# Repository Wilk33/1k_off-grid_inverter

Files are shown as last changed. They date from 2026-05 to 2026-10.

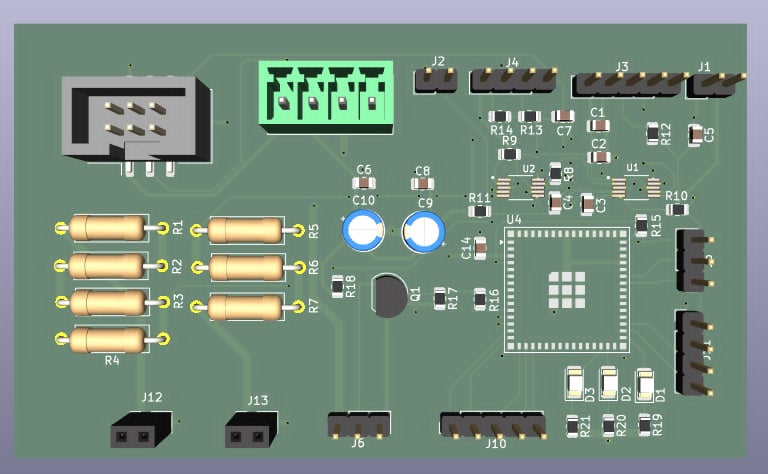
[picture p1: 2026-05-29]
hardware/MCU_measurements/pcb_kicad_3d.png

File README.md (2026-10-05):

# Off-Grid 1kW Inverter (24V DC -> 230V AC)

> [!IMPORTANT]
> **Projekt został zamknięty i nie będzie dalej rozwijany.**
>
> Repozytorium pozostaje archiwum dotychczasowego kodu i dokumentacji. Nie są planowane kolejne etapy, poprawki ani nowe wydania.

Projekt przetwornicy off-grid o mocy 1 kW przeznaczonej do konwersji napięcia z instalacji 24V DC na napięcie sieciowe 230V AC 50Hz.
Urządzenie składa się z dwóch głównych stopni konwersji energii:

1. Przetwornica DC/DC podwyższająca napięcie z 24V do około 325V DC
2. Falownik DC/AC generujący napięcie 230V AC 50Hz

System sterowany jest przez mikrokontroler odpowiedzialny za generację sygnałów sterujących, pomiary oraz zabezpieczenia.

---

# Główne parametry

| Parametr | Wartość |
| --- | --- |
| Moc znamionowa | 1000W |
| Napięcie wejściowe | 24V DC |
| Napięcie pośrednie | ~325V DC |
| Napięcie wyjściowe | 230V AC |
| Częstotliwość | 50Hz |
| Typ pracy | Off-grid |
| Sterowanie | Mikrokontroler |

---

# Architektura systemu

System składa się z kilku głównych bloków funkcjonalnych:

24V DC
↓
DC/DC Boost Converter
↓
325V DC Bus
↓
Full Bridge Inverter
↓
LC Filter
↓
230V AC 50Hz

Dodatkowo system zawiera:

* sterowniki bramek tranzystorów mocy
* układy pomiarowe prądu i napięcia
* system chłodzenia

---

# Moduły projektu

## 1. Przetwornica DC/DC (24V -> 325V)

Odpowiada za podwyższenie napięcia z poziomu akumulatora do napięcia magistrali DC.

Główne elementy:

* transformator wysokiej częstotliwości
* tranzystory MOSFET
* sterowniki bramek

---

## 2. Falownik (325V DC -> 230V AC)

Falownik generuje napięcie sinusoidalne poprzez modulację PWM.

Topologia:

Full Bridge (H-Bridge)

Sterowanie:

SPWM (Sinusoidal Pulse Width Modulation)

Elementy:

* tranzystory MOSFET / IGBT
* drivery bramek
* filtr LC

---

## 3. Mikrokontroler

Mikrokontroler jest centralną jednostką sterującą systemem.

Zadania:

* generowanie sygnałów PWM
* sterowanie przetwornicą DC/DC
* sterowanie falownikiem
* pomiar napięcia i prądu
* implementacja zabezpieczeń
* diagnostyka systemu

---

## 4. Sterowniki elementów mocy

Sterowniki bramek odpowiadają za szybkie i bezpieczne przełączanie tranzystorów.

Wymagania:

* izolacja galwaniczna
* odpowiedni prąd sterowania bramki
* kontrola dead-time
* ochrona przed zwarciem

---

## 5. Pomiar prądu i napięcia

Układ pomiarowy pozwala na monitorowanie parametrów pracy systemu.

Pomiar obejmuje:

* napięcie wejściowe
* napięcie magistrali DC
* napięcie wyjściowe AC
* prąd wyjściowy

Stosowane elementy:

* rezystory pomiarowe
* czujniki Halla
* dzielniki napięcia

---

## 6. Konstrukcja mechaniczna

Projekt mechaniczny obejmuje:

* obudowę
* system chłodzenia
* rozmieszczenie PCB
* radiatory dla elementów mocy

---

# Struktura repozytorium

```
hardware/ 
    dcdc_converter/
    drivers/
    inverter/
    measurements/

firmware/
    mcu_control/
    pwm_generation/
    measurements/
    protection/
```

---

# Etapy projektu

1. Projekt architektury systemu
2. Projekt przetwornicy DC/DC
3. Projekt falownika
4. Implementacja firmware mikrokontrolera
5. Projekt PCB

---

# Licencja

Projekt open hardware / open source.

---

# Autorstwo i status

Projekt był tworzony przez Codex GPT-5.6-Sol pod kierunkiem Mateusza Skipora, na podstawie jego wymagań i decyzji projektowych.

Status końcowy: projekt zamknięty, bez dalszego rozwoju.

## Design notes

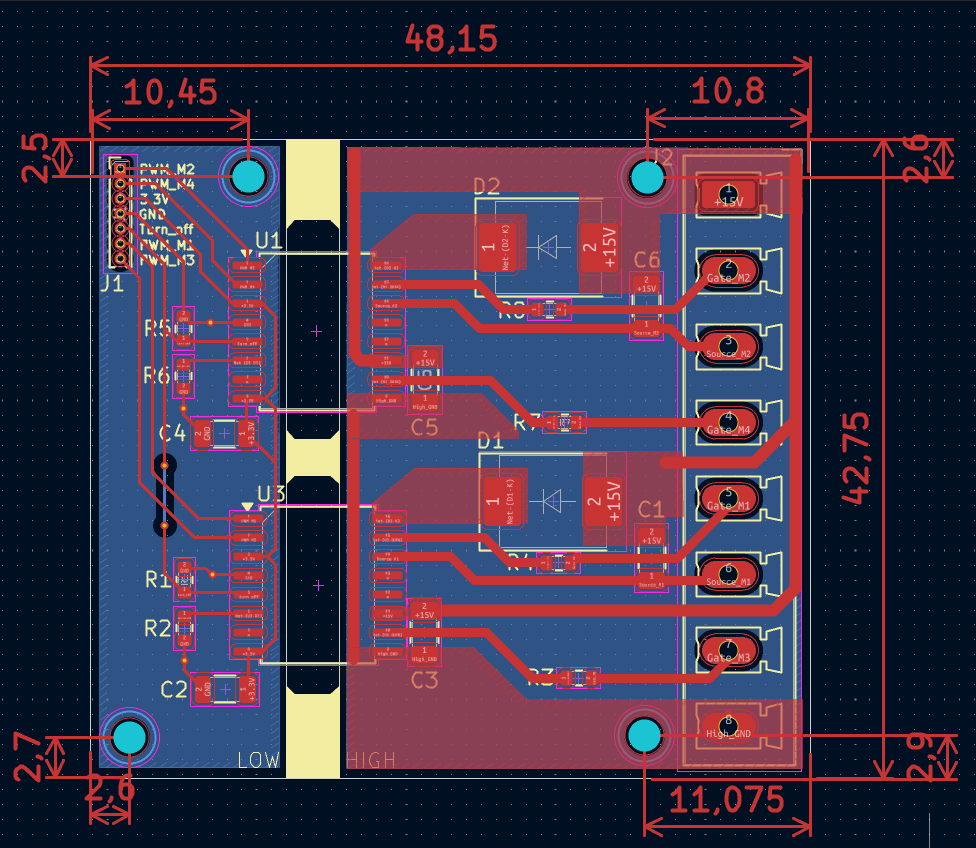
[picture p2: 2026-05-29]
hardware/drivers/Wymiary.png

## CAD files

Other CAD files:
hardware/MCU_measurements/projekt falownik/falownik.f3d

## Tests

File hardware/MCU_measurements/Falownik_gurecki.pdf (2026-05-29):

## Dokumentacja techniczna projektu

# Falownik off-grid 1 kW

## 24 V DC - 230 V AC 50 Hz

Scrum Master: | Mateusz Skipor
Project Owner: | Jakub Wacławczyk
Repozytorium: | Wilk33/1k_off-grid_inverter
Charakter dokumentu: | Dokumentacja techniczna projektu koncepcyjnego

29 maja 2026

## Spis treści

1 Wstęp | 2
2 Cel projektu | 2
3 Założenia projektowe | 2
4 Podstawowe parametry projektu | 2
5 Ogólna architektura urządzenia | 3
6 Zrealizowane moduły sprzętowe | 3
7 Układ pomiarowy | 9
8 Płytka pomiarów DC i sterowania | 10
9 Obudowa i chłodzenie | 12
10 Firmware | 14
11 Struktura repozytorium | 14
12 Organizacja pracy zespołu | 15
13 Aktualny stan realizacji projektu | 16
14 Podsumowanie | 16
15 Wnioski członków zespołu | 16

1 z 17

## 1 Wstęp

Niniejszy dokument przedstawia dokumentację techniczną projektu koncepcyjnego falownika off-grid o mocy znamionowej 1 kW. Projekt został przygotowany jako opracowanie techniczne obejmujące ogólną architekturę urządzenia, podział na główne bloki funkcjonalne, opis wykonanych modułów sprzętowych oraz zakres elementów pozostających do dalszego opracowania.
Projektowany układ ma za zadanie przekształcać napięcie stałe 24 V DC na napięcie przemienne 230 V AC o częstotliwości 50 Hz. Przyjęto strukturę dwustopniową, w której pierwszy stopień odpowiada za podwyższenie napięcia wejściowego do poziomu szyny pośredniej, natomiast drugi stopień realizuje przekształcenie napięcia stałego na napięcie przemienne.
Dokumentacja nie stanowi instrukcji produkcyjnej ani kompletnej dokumentacji wykonawczej gotowego urządzenia. Jej celem jest przedstawienie przyjętej koncepcji technicznej, wykonanych elementów projektu, podziału prac w zespole oraz zakresu prac pozostających do dalszego opracowania.

## 2 Cel projektu

Celem projektu jest opracowanie falownika off-grid o mocy znamionowej 1 kW, przeznaczonego do pracy z wejściowym źródłem napięcia stałego 24 V DC. Urządzenie ma generować napięcie wyjściowe 230 V AC o częstotliwości 50 Hz.
Projekt obejmuje opracowanie głównych bloków sprzętowych, takich jak przetwornica DC/DC, falownik DC/AC, sterownik mostka H, układ pomiarowy, chłodzenie, część sterująca oraz obudowa. Część programowa ma zostać przygotowana jako firmware dla mikrokontrolera ESP.

## 3 Założenia projektowe

Podstawowym założeniem projektu jest zastosowanie dwustopniowej konwersji energii. Pierwszy stopień odpowiada za przekształcenie napięcia 24 V DC do poziomu szyny pośredniej około 325-340 V DC. Drugi stopień, zasilany z tej szyny, odpowiada za wytworzenie napięcia przemiennego 230 V AC.
Przyjęto, że sterowanie układem będzie realizowane przez mikrokontroler ESP. Część sterująca ma odpowiadać za generację sygnałów PWM, obsługę pomiarów, podstawową diagnostykę oraz sterowanie stanami pracy urządzenia.
Podstawowa komunikacja z użytkownikiem ma być realizowana za pomocą trzech diod LED. Rozwiązanie to pozwala sygnalizować podstawowe stany pracy urządzenia, takie jak zasilanie, praca poprawna lub błąd. Projekt zakłada również możliwość późniejszej rozbudowy komunikacji o wyświetlacz I2C.

## 4 Podstawowe parametry projektu

Tabela 1: Podstawowe parametry projektowanego falownika

Parametr | Wartość
Moc znamionowa | 1000 W
Napięcie wejściowe | 24 V DC
Napięcie szyny pośredniej | około 325-340 V DC
Napięcie wyjściowe | 230 V AC
Częstotliwość wyjściowa | 50 Hz
Rodzaj pracy | off-grid
Mikrokontroler | ESP
Podstawowa komunikacja | 3 diody LED
Możliwość rozbudowy komunikacji | wyświetlacz I2C
Metoda sterowania falownikiem | PWM / SPWM

## 5 Ogólna architektura urządzenia

Projektowany falownik składa się z kilku podstawowych bloków funkcjonalnych. Energia dostarczana jest ze źródła napięcia stałego 24 V DC. Następnie napięcie wejściowe jest podwyższane przez przetwornicę DC/DC do poziomu napięcia szyny pośredniej. Z szyny pośredniej zasilany jest falownik DC/AC, którego zadaniem jest wygenerowanie napięcia przemiennego. Na wyjściu przewidziano filtr LC, którego zadaniem jest ograniczenie składowych wynikających z przełączania tranzystorów mocy.
Przyjęta struktura urządzenia ma postać:

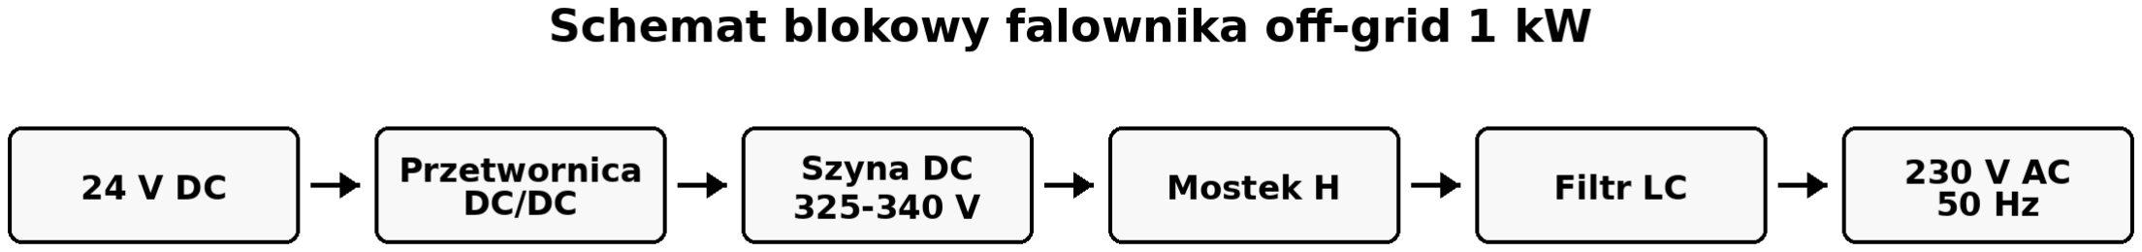
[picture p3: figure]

Rys. 1: Schemat blokowy falownika off-grid 1 kW

Nad pracą układu czuwa mikrokontroler ESP. Do jego zadań należy generowanie sygnałów sterujących, odczyt pomiarów, analiza stanu pracy oraz sygnalizacja stanu urządzenia za pomocą diod LED.

## 6 Zrealizowane moduły sprzętowe

Na obecnym etapie projektu przygotowano kilka modułów sprzętowych w postaci projektów PCB oraz widoków 3D. Moduły te obejmują płytkę przetwornicy DC/DC, płytkę sterownika mostka H oraz płytkę falownika DC/AC z mostkiem H i filtrem LC. W kolejnych podrozdziałach opisano ich przeznaczenie oraz rolę w całym układzie.

### 6.1 Płytka przetwornicy DC/DC

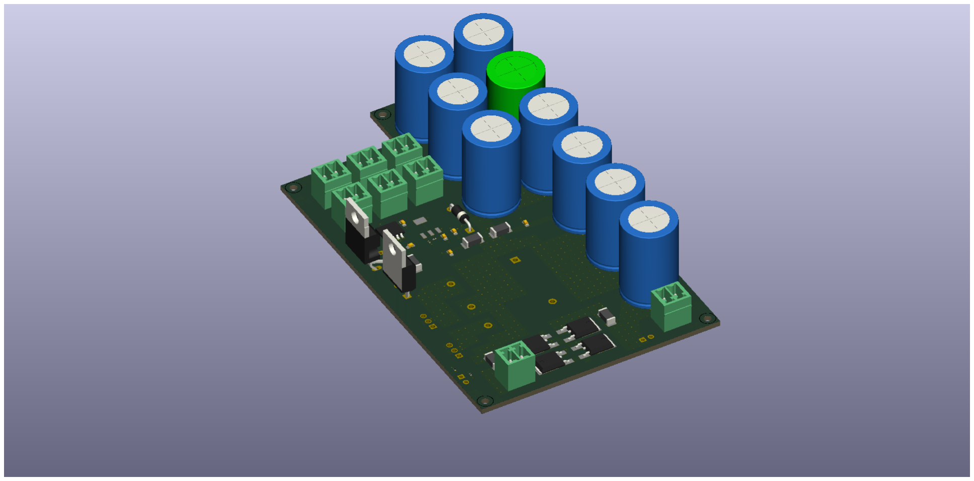
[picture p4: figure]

Rys. 2: Widok 3D płytki przetwornicy DC/DC odpowiedzialnej za wytworzenie napięć zasilających układ

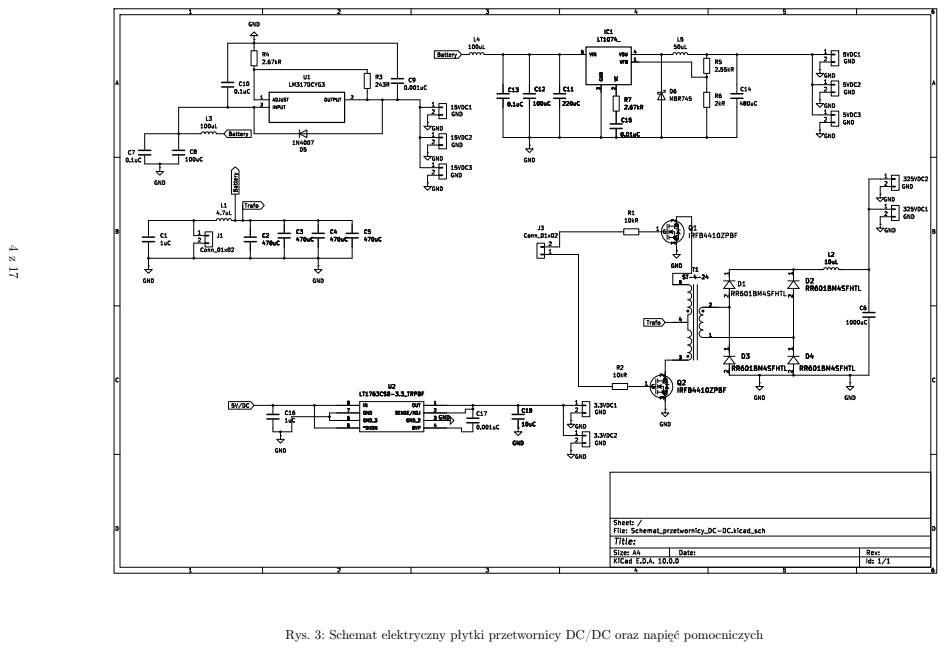
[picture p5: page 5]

Rys. 3: Schemat elektryczny płytki przetwornicy DC/DC oraz napięć pomocniczych

Płytka przetwornicy DC/DC stanowi jeden z głównych bloków zasilających projektowanego falownika. Odpowiada ona za przygotowanie napięć potrzebnych do pracy układu, w tym napięcia wysokiego dla szyny pośredniej oraz napięć logicznych i pomocniczych wymaganych przez pozostałe moduły.
Za projekt płytki przetwornika napięć DC/DC odpowiadał Łukasz Rasztar. Zakres jego prac obejmował nie tylko przetwornik wysokiego napięcia, ale również przygotowanie napięć logicznych i zasilających dla pozostałych części systemu.
Na płytce widoczne są złącza przyłączeniowe, elementy półprzewodnikowe oraz duża liczba kondensatorów elektrolitycznych. Kondensatory pełnią funkcję magazynowania energii oraz stabilizacji napięcia w torze zasilania. Złącza śrubowe umożliwiają doprowadzenie przewodów zasilających oraz połączenie modułu z pozostałymi częściami projektu.
Zastosowanie oddzielnej płytki przetwornicy DC/DC pozwala wydzielić blok zasilania jako osobny moduł. Ułatwia to opis projektu, późniejszą analizę układu oraz ewentualną modyfikację samego stopnia zasilającego.

### 6.2 Płytka sterująca mostkiem H

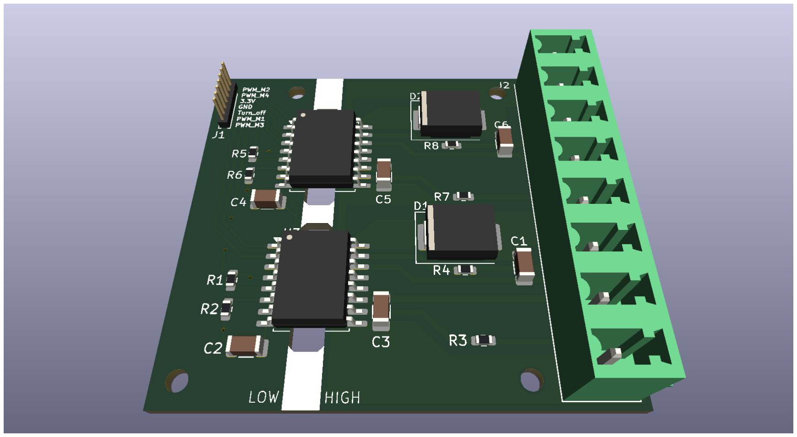
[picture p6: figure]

Rys. 4: Widok 3D płytki sterującej mostkiem H

Płytka sterująca mostkiem H pełni funkcję pośredniczącą pomiędzy mikrokontrolerem ESP a tranzystorami mocy pracującymi w mostku H. Na wejściu płytki przewidziano sygnały PWM oraz zasilanie części logicznej. Na widoku płytki można zauważyć opisy wejść: PWM_M1, PWM_M2, PWM_M3, PWM_M4, 3.3V oraz GND. Za projekt płytki sterującej mostkiem H odpowiadał Tobiasz Kondziora. Przygotowany moduł umożliwia doprowadzenie sygnałów sterujących do elementów wykonawczych falownika.
Na płytce znajdują się dwa większe układy scalone, elementy bierne oraz elementy wykonawcze po stronie wyjściowej. Widoczne oznaczenia LOW oraz HIGH wskazują na podział sterowania na część dolną i górną, co odpowiada strukturze sterowania tranzystorami pracującymi w układzie mostka H.
Zastosowanie oddzielnego modułu sterującego mostkiem H porządkuje strukturę projektu. Sygnały logiczne generowane przez mikrokontroler mogą zostać doprowadzone do tej płytki, a następnie przekształcone na sygnały odpowiednie do sterowania elementami mocy.

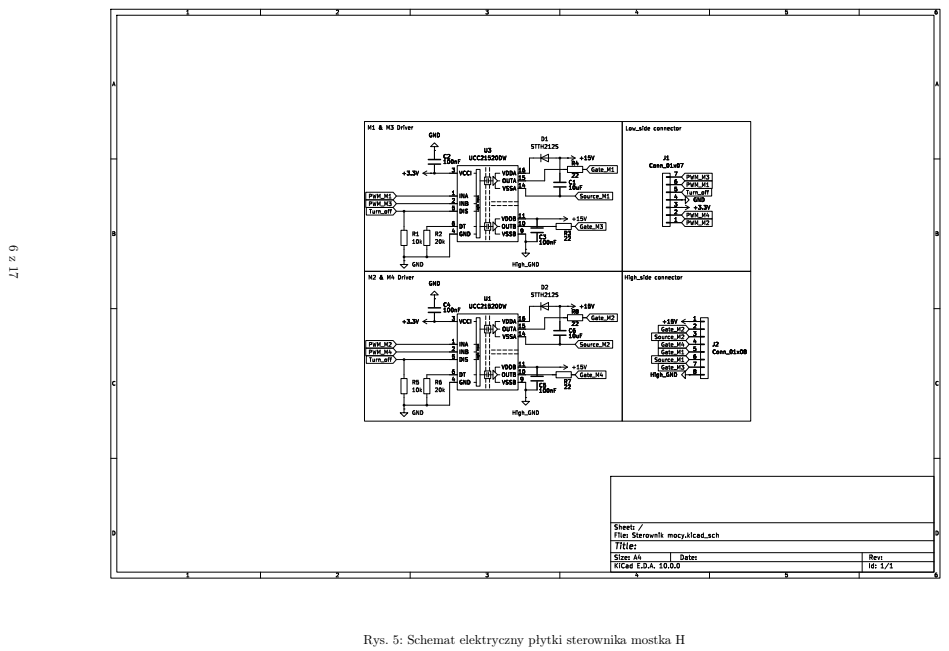
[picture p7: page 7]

Rys. 5: Schemat elektryczny płytki sterownika mostka H

### 6.3 Płytka falownika DC/AC

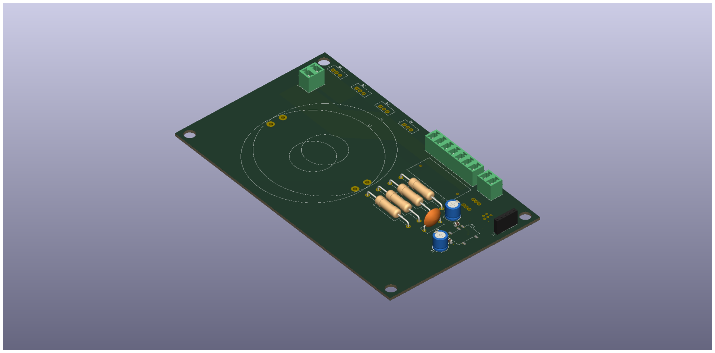
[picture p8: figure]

Rys. 6: Widok 3D płytki falownika DC/AC z mostkiem H i filtrem LC

Płytka falownika DC/AC stanowi drugi główny stopień przekształcania energii. Jej zadaniem jest zamiana napięcia stałego szyny pośredniej na napięcie przemienne o wartości 230 V AC i częstotliwości 50 Hz.
Za filtr LC oraz mostek H płytki inwertera odpowiadał Grzegorz Rak. Mostek H jest częścią wykonawczą odpowiedzialną za przełączanie napięcia szyny pośredniej, natomiast filtr LC ogranicza składowe wysokoczęstotliwościowe i pozwala uzyskać przebieg wyjściowy zbliżony do sinusoidalnego.
Na płytce widoczne są złącza przyłączeniowe, elementy bierne, układy scalone oraz miejsce przeznaczone na większy element indukcyjny lub filtrujący. Część ta jest związana z obróbką przebiegu wyjściowego i ograniczeniem składowych wynikających z impulsowego charakteru sterowania tranzystorami.
Płytka falownika została zaprojektowana jako osobny moduł, co ułatwia rozdzielenie stopnia zasilającego od stopnia generującego napięcie przemienne. Taki podział odpowiada przyjętej architekturze całego urządzenia.

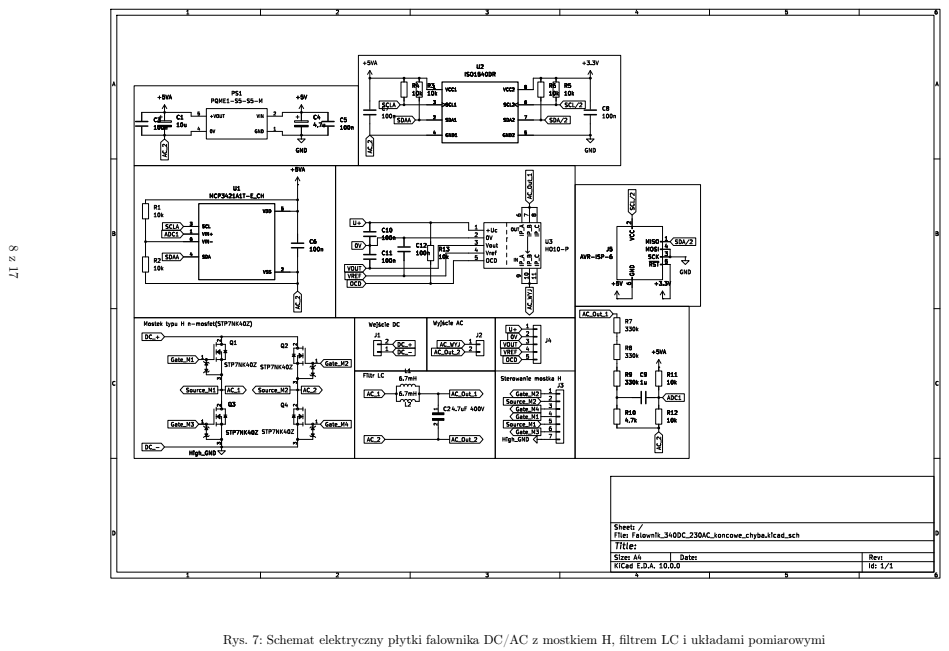
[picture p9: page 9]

Rys. 7: Schemat elektryczny płytki falownika DC/AC z mostkiem H, filtrem LC i układami pomiarowymi

## 7 Układ pomiarowy

Za projekt układu pomiarowego odpowiadał Mateusz Skipor. Układ pomiarowy został zaplanowany jako część nadzorująca podstawowe wielkości elektryczne i temperaturowe występujące w falowniku. Samo wdrożenie układu pomiarowego zostało rozdzielone pomiędzy płytki wykonawcze, aby pomiary znajdowały się możliwie blisko kontrolowanych sekcji.
W projekcie przewidziano pomiary napięć AC i DC, pomiary prądów oraz pomiary temperatury. Pomiar DC obejmuje główną szynę 325 V DC oraz baterię 24 V. Pomiar AC dotyczy napięcia oraz prądu po stronie wyjściowej falownika. Pomiary prądu zaplanowano z wykorzystaniem czujników Halla.

### 7.1 Pomiary napięć DC

Pomiary napięć DC obejmują napięcie baterii 24 V oraz napięcie głównej szyny pośredniej około 325 V DC. Ze względu na różnicę poziomów napięć, każdy z tych pomiarów wymaga odpowiedniego dopasowania do zakresu wejściowego układu pomiarowego mikrokontrolera.
W pomiarach wysokich napięć zastosowano dzielniki rezystorowe wykonane z kilku rezystorów THT połączonych szeregowo. W praktyce przewidziano po 3-4 rezystory w szeregu. Takie rozwiązanie zmniejsza ryzyko przebicia na pojedynczym elemencie, ponieważ napięcie rozkłada się na kilka rezystorów zamiast odkładać się na jednym.

### 7.2 Pomiary napięć i prądów AC

Po stronie AC przewidziano pomiar napięcia wyjściowego oraz prądu obciążenia. Pomiar napięcia pozwala nadzorować wartość napięcia generowanego przez falownik, natomiast pomiar prądu pozwala określić obciążenie układu.
Pomiary prądu realizowane są za pomocą czujników Halla. Zastosowanie takich czujników upraszcza pomiar prądu w torze mocy i pozwala oddzielić sygnał pomiarowy od głównej ścieżki prądowej.

### 7.3 Pomiary temperatury

W projekcie przewidziano dwa czujniki temperatury. Pierwszy czujnik znajduje się na radiatorze sekcji DC/DC, a drugi na radiatorze mostka H. Pozwala to osobno kontrolować temperaturę dwóch głównych obszarów, w których mogą występować największe straty mocy.
Pomiar temperatury może zostać wykorzystany przez firmware do sygnalizacji stanu pracy lub do ograniczenia działania układu w przypadku przekroczenia dopuszczalnej temperatury.

## 8 Płytka pomiarów DC i sterowania

Za projekt płytki pomiarów DC i sterowania odpowiada Jakub Wacławczyk. Moduł ten stanowi centralny element systemu sterowania falownika i odpowiada za integrację funkcji pomiarowych, sterujących oraz komunikacyjnych.


Rys. 8: Widok 3D płytki pomiarów DC i sterowania

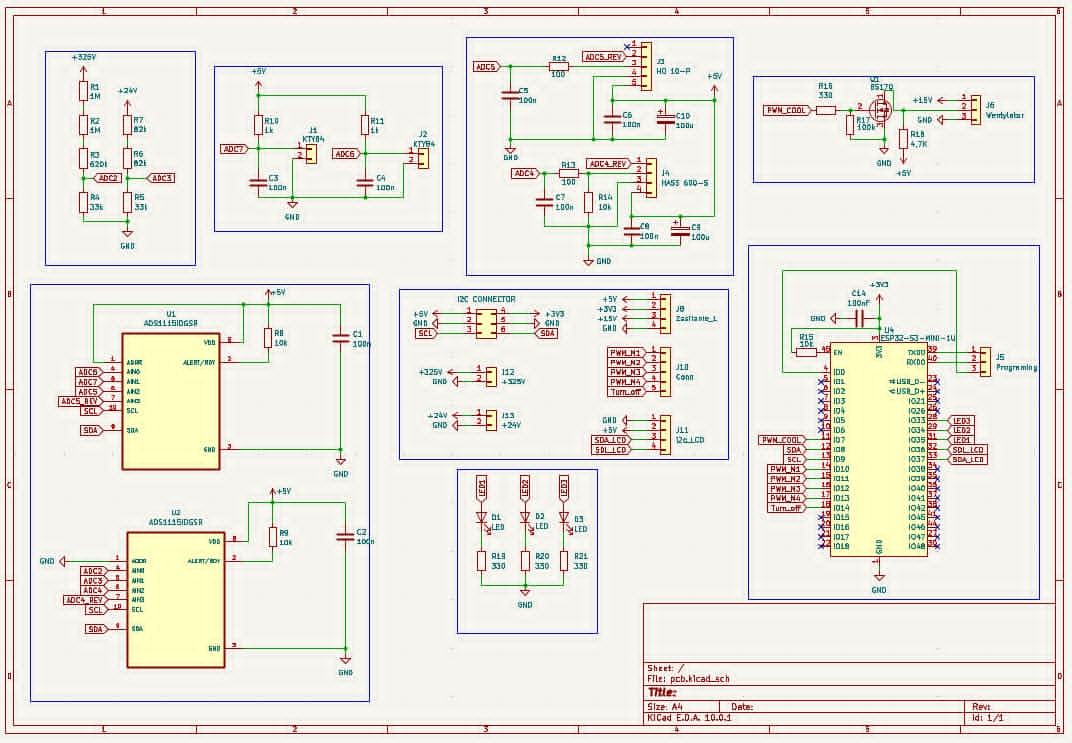
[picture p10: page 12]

Rys. 9: Schemat elektryczny płytki pomiarów DC i sterowania

11 z 17

Sercem układu jest mikrokontroler ESP32-S3, odpowiedzialny za realizację algorytmów sterowania, obsługę pomiarów oraz komunikację pomiędzy poszczególnymi modułami falownika. Na płytce umieszczono również dwa przetworniki analogowo-cyfrowe ADS1115 komunikujące się za pomocą magistrali I2C. Pozwalają one zwiększyć liczbę dostępnych wejść pomiarowych oraz poprawić rozdzielczość pomiarów napięć i sygnałów analogowych. Układ umożliwia realizację pomiarów napięcia wejściowego 24 V DC oraz napięcia szyny pośredniej około 325 V DC. W tym celu zastosowano dzielniki rezystorowe dopasowujące poziomy napięć do zakresu wejść przetworników ADC. Dodatkowo przewidziano wejścia przeznaczone do współpracy z czujnikami temperatury oraz czujnikami Halla wykorzystywanymi do pomiaru prądów.
Na płytce znajdują się również złącza umożliwiające podłączenie sygnałów PWM, magistrali I2C, czujników temperatury oraz modułów wykonawczych. Przewidziano także wyprowadzenia pozwalające na późniejszą rozbudowę systemu o wyświetlacz komunikujący się poprzez magistralę I2C.
Podstawowa komunikacja z użytkownikiem realizowana jest za pomocą trzech diod LED sygnalizujących stan pracy urządzenia. Dodatkowo zastosowano tranzystorowy układ sterowania wentylatorem chłodzącym, którego prędkość może być regulowana sygnałem PWM generowanym przez mikrokontroler.
Zakres funkcjonalny płytki obejmuje:
- obsługę mikrokontrolera ESP32-S3,
- pomiar napięcia wejściowego 24 V DC,
- pomiar napięcia szyny pośredniej 325 V DC,
- współpracę z czujnikami Halla,
- obsługę dwóch czujników temperatury,
- dystrybucję sygnałów PWM,
- sterowanie wentylatorem chłodzenia,
- komunikację poprzez magistralę I2C,
- sygnalizację stanu pracy za pomocą trzech diod LED,
- możliwość rozbudowy o wyświetlacz I2C.

Płytka pełni funkcję nadrzędnego modułu sterującego integrującego pozostałe bloki falownika i odpowiada za nadzorowanie parametrów pracy całego urządzenia.

## 9 Obudowa i chłodzenie

Za projekt obudowy oraz systemu chłodzenia odpowiada Jakub Wacławczyk. Obudowa została przygotowana jako dedykowana konstrukcja mechaniczna przeznaczona do integracji wszystkich modułów falownika w jednej zwartej konstrukcji.

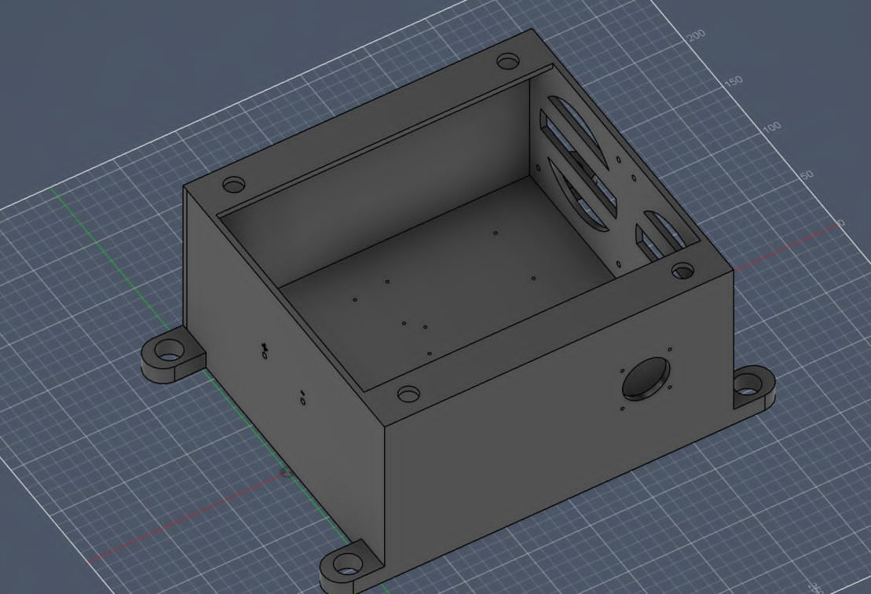
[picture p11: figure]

Rys. 10: Model 3D obudowy - widok wnętrza

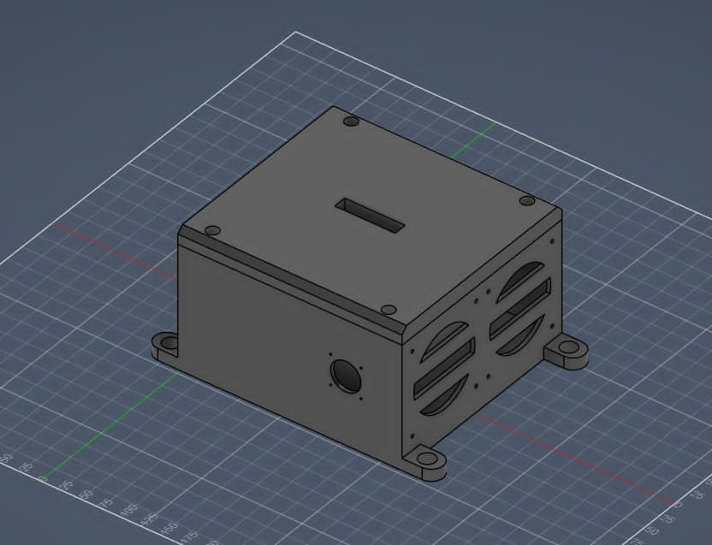
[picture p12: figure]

Rys. 11: Model 3D obudowy - widok zewnętrzny

Projekt obudowy uwzględnia rozmieszczenie płytek elektronicznych, przepustów kablowych oraz elementów chłodzących. W konstrukcji przewidziano otwory montażowe umożliwiające trwałe zamocowanie urządzenia do podłoża oraz wewnętrzne punkty mocowania dla modułów elektronicznych.
Na bocznych ścianach obudowy umieszczono otwory przeznaczone dla złączy, przewodów oraz elementów wentylacyjnych. W górnej pokrywie przewidziano dodatkowy otwór umożliwiający montaż elementów sygnalizacyjnych lub poprawę przepływu powietrza wewnątrz urządzenia.

W projekcie przewidziano chłodzenie aktywne wspomagane wentylatorem sterowanym przez płytkę pomiarów DC i sterowania. Praca układu chłodzenia ma być uzależniona od temperatury monitorowanej przez dwa czujniki temperatury umieszczone na radiatorze sekcji DC/DC oraz radiatorze mostka H.
Zastosowanie osobnych punktów pomiarowych umożliwia niezależne monitorowanie temperatury obu głównych sekcji mocy falownika. Pozwala to na realizację zabezpieczeń termicznych oraz automatyczną regulację intensywności chłodzenia w zależności od aktualnych warunków pracy urządzenia.
Przygotowany model stanowi kompletną koncepcję mechaniczną przeznaczoną do dalszych prac związanych z wykonaniem fizycznego prototypu urządzenia.

## 10 Firmware

Za oprogramowanie odpowiada Marcin Majchrowski. Kod programu sterującego nie jest jeszcze ukończony. W docelowej wersji projektu firmware będzie odpowiadał za generację sygnałów PWM, obsługę pomiarów oraz sterowanie pracą poszczególnych modułów.
Firmware ma pracować na mikrokontrolerze ESP. Do jego zadań będzie należeć odczyt wartości pomiarowych, generacja sygnałów sterujących oraz obsługa podstawowej sygnalizacji stanu urządzenia.
Zakładane zadania firmware:
- generowanie sygnałów PWM dla stopnia mocy,
- realizacja modulacji SPWM dla falownika,
- odczyt napięcia baterii 24 V,
- odczyt napięcia szyny pośredniej 325 V DC,
- odczyt napięcia i prądu AC,
- odczyt prądów z czujników Halla,
- odczyt temperatury radiatora sekcji DC/DC,
- odczyt temperatury radiatora mostka H,
- obsługa trzech diod LED,
- możliwość późniejszej obsługi wyświetlacza I2C,
- obsługa stanów pracy urządzenia,
- diagnostyka pracy układu.

Na potrzeby obecnej dokumentacji firmware opisano jako część planowaną do uzupełnienia. Po dodaniu kodu do repozytorium rozdział ten może zostać rozszerzony o opis struktury programu, funkcje poszczególnych plików oraz przykładowe fragmenty kodu.

## 11 Struktura repozytorium

Repozytorium projektu zostało podzielone na część sprzętową oraz część programową. Część sprzętowa obejmuje projekty modułów elektronicznych, natomiast część programowa jest przeznaczona na kod mikrokontrolera. Przykładowa struktura repozytorium:

hardware/

dcdc_converter/

drivers/

inverter/

measurements/

firmware/

mcu_control/

pwm_generation/

measurements/

protection/

Taki podział pozwala uporządkować projekt i oddzielić dokumentację sprzętu od kodu programu. Ułatwia również późniejsze rozwijanie projektu przez kilka osób.

## 12 Organizacja pracy zespołu

Projekt został podzielony pomiędzy członków zespołu według głównych obszarów funkcjonalnych. Taki podział pozwolił rozdzielić prace nad przetwornicą, falownikiem, sterowaniem, pomiarami, obudową i oprogramowaniem.

Tabela 2: Podział ról i odpowiedzialności w projekcie

Osoba | Rola | Zakres odpowiedzialności
Mateusz Skipor | Scrum Master | Koordynacja projektu, projekt układu pomia-rowego, podział wdrożenia pomiarów na płyt-ki wykonawcze
Jakub Wacławczyk | Project Owner | Obudowa, płytka sterująca, chłodzenie, wdro-żenie sekcji pomiarowej DC
Grzegorz Rak | Członek zespołu | Filtr LC oraz mostek H płytki inwertera
Łukasz Rasztar | Członek zespołu | Projekt płytki przetwornika napięć DC/DC, w tym napięcia wysokiego, logiczne i zasilające
Marcin Majchrowski | Członek zespołu | Oprogramowanie mikrokontrolera
Tobiasz Kondziora | Członek zespołu | Projekt płytki sterującej mostkiem H

## 13 Aktualny stan realizacji projektu

Na obecnym etapie przygotowano podstawową koncepcję techniczną falownika oraz wykonano projekty kilku modułów sprzętowych. Dostępne są widoki 3D płytek: przetwornicy DC/DC, sterownika mostka H oraz falownika DC/AC.

Tabela 3: Aktualny stan realizacji głównych części projektu

Element projektu | Status | Uwagi
Przetwornica DC/DC | Opracowana | Dostępny projekt płytki i widok 3D
Sterownik mostka H | Opracowany | Dostępny projekt płytki i widok 3D
Falownik DC/AC | Opracowany | Dostępny projekt płytki i widok 3D
Filtr LC | Opracowany jako część płytki inwertera | Odpowiada za filtrację przebiegu wyjściowego
Układ pomiarowy | Opracowany koncepcyjnie | Wdrożenie rozdzielone na płytki wykonawcze
Płytka pomiarów DC i sterowania | Opracowany | Dostępny schemat oraz model PCB
Obudowa | Opracowany | Dostępny model 3D obudowy
Chłodzenie | Opracowany | Przewidziano radiatory sekcji DC/DC i mostka H
Firmware | Do uzupełnienia | Kod zostanie dodany w dalszym etapie

## 14 Podsumowanie

W ramach projektu opracowano koncepcję falownika off-grid o mocy 1 kW, przeznaczonego do przekształcania napięcia 24 V DC na napięcie 230 V AC 50 Hz. Przyjęto dwustopniową strukturę konwersji energii, obejmującą przetwornicę DC/DC oraz falownik DC/AC z mostkiem H i filtrem LC.
Na obecnym etapie przygotowano projekty wybranych modułów sprzętowych, w tym płytki przetwornicy DC/DC, sterownika mostka H oraz falownika DC/AC. Opracowano również założenia układu pomiarowego obejmującego pomiary napięć DC i AC, pomiary prądów za pomocą czujników Halla oraz pomiary temperatury radiatorów sekcji DC/DC i mostka H.
Do dalszego opracowania pozostaje płytka pomiarów DC i sterowania, firmware mikrokontrolera ESP, projekt obudowy oraz chłodzenie. Przygotowana dokumentacja przedstawia podstawowe założenia projektowe, parametry układu, opis głównych bloków funkcjonalnych, podział odpowiedzialności w zespole oraz aktualny stan realizacji projektu.

## 15 Wnioski członków zespołu

### 15.1 Wnioski Scrum Mastera - Mateusz Skipor

Praca zespołowa podczas realizacji projektu nie przebiegała idealnie. W trakcie realizacji napotkano kilka problemów organizacyjnych oraz technicznych, które miały wpływ na tempo wykonywania poszczególnych zadań. Pierwszym problemem była konieczność równoległej pracy kilku osób nad zagadnieniami silnie powiązanymi ze sobą. Komunikacja pomiędzy członkami zespołu nie przebiegała bezpośrednio w stopniu pozwalającym na sprawną współpracę techniczną, przez co większość wymiany informacji odbywała się za pośrednictwem Scrum Mastera. W rezultacie konieczne było dostosowanie zakresu prac poszczególnych członków zespołu w taki sposób, aby mogli oni pracować możliwie niezależnie od siebie. Z tego powodu zrezygnowano również z koncepcji wykonania jednej wspólnej płytki PCB integrującej wszystkie funkcje urządzenia. Każdy członek zespołu opracowywał własny moduł sprzętowy realizujący przydzieloną część funkcjonalności projektu.
Drugim problemem były opóźnienia wynikające z obowiązków prywatnych oraz dużego obciążenia pracą związaną z innymi przedmiotami realizowanymi w tym samym semestrze. Powodowało to okresowe przesunięcia terminów wykonania niektórych elementów projektu.
Kolejny problem wynikał z różnic pomiędzy środowiskami projektowymi wykorzystywanymi przez członków zespołu. Powodowało to dodatkowe trudności przy wymianie materiałów projektowych oraz integracji wyników prac poszczególnych osób.
Pomimo występujących problemów wszystkie napotkane trudności zostały rozwiązane w trakcie realizacji projektu. Ostatecznie zespół zrealizował założone cele oraz zakończył prace w wyznaczonym terminie.

### 15.2 Wnioski Project Ownera - Jakub Wacławczyk

Projekt został zrealizowany zgodnie z przyjętymi założeniami funkcjonalnymi oraz ukończony w zakładanym terminie. Większość obowiązków została wykonana zgodnie z pierwotnym podziałem zadań, jednak w trakcie realizacji konieczne były drobne zmiany organizacyjne wynikające z bieżących potrzeb projektu oraz konieczności dostosowania harmonogramu prac.
Jednym z głównych problemów organizacyjnych był początkowo niewystarczająco szczegółowy podział obowiązków pomiędzy członków zespołu. Część zadań wymagała dodatkowej koordynacji oraz doprecyzowania odpowiedzialności poszczególnych osób. W niektórych przypadkach konieczne było również poświęcenie większej ilości czasu na realizację określonych etapów projektu niż zakładano pierwotnie.
Do zarządzania projektem wykorzystano repozytorium GitHub, komunikator Messenger oraz platformę Discord. Narzędzia te okazały się wystarczające do prowadzenia prac projektowych oraz wymiany informacji pomiędzy członkami zespołu.
Zdobyte doświadczenia wskazują, że w przyszłych projektach warto poświęcić więcej czasu na szczegółowe planowanie działań, dokładne określenie zakresu obowiązków każdego członka zespołu oraz wprowadzenie większej kontroli nad realizacją ustalonych terminów. Pomimo napotkanych trudności projekt został ukończony prawidłowo, a wszystkie istotne problemy zostały rozwiązane w trakcie jego realizacji.

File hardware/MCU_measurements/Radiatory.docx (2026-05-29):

1. Obliczenia dla czterech nmosfetów stm11nm80.
  a. Dane:
    i. Rth j-c (opór termiczny złącze- obudowa) = 0,83 oC/W
    ii. Tj max (maksymalna temperatura złącza = 150oC (dla obliczeń przyjęto 125oC)
    iii. Ptot max (przy 25oC) = 150W
    iv. Pd (odczytane z symulacji) = 11,6W
    v. Rth c-s (opór obudowa – radiator)(podkładka) = 0,4oC/W
    vi. Totocz= 25oC
  b. Obliczenia:
    i. Ptot = 4*11,6 = 46,4W
    ii. 125 = Ts + 11,6*(0,83+0,4)
    iii. Ts = 110,73oC
    iv. Tj-s = 11,6*(0,83+0,4)=14,268oC
    v. Rth s-a ≤(110,73-25)/46,4
    vi. Rth s-a ≤1,85oC/W
  c. Sprawdzenie:


2. 2x IRFB4410ZPBF, MBR745, LT1074
  a. Dane dla IRFB4410ZPBF
    i. Rth j-c (opór termiczny złącze- obudowa) = 0,65 oC/W
    ii. Pd (odczytane z symulacji) = 13W
    iii. Tj max = 175oC
  b. Dane dla MBR745
    i. Rth j-c (opór termiczny złącze- obudowa) = 3 oC/W
    ii. Pd (odczytane z symulacji) = 25W
    i. Tj max = 150oC
  c. Dane dla LT1074
    i. Rth j-c (opór termiczny złącze- obudowa) = 2,5 oC/W
    ii. Pd (odczytane z symulacji) = 10W
    i. Tj max = 125oC
  d. Użyto tych samych termalpadów co poprzednio
  e. Obliczenia
    i. Ptot = 61W
    i. Dla IRFB4410ZPBF
      1. Tj-s=13*(0,65+0,4)=13,65oC
      2. Ts max=175-13,65=161,35oC
    i. Dla MBR745
      1. Tj-s=25*(3+0,4)=85oC
      2. Ts max=150-85=65oC
    i. Dla IRFB4410ZPBF
      1. Tj-s=10*(2,5+0,4)=29oC
      2. Ts max=125-29=96oC
    i. Rth s-a ≤(65-25)/61
    ii. Rth s-a ≤0,66oC/W


3. 4x RR601BM4S
  a. Dane:
    i. Rth j-c (opór termiczny złącze- obudowa) =6 oC/W
    ii. Tj max (maksymalna temperatura złącza = 150oC (dla obliczeń przyjęto 125oC)
    iii. Pd (odczytane z symulacji) = 15W
    iv. Rth c-s (opór obudowa – radiator)(podkładka) = 0,4oC/W
    v. Totocz= 25oC
  b. Obliczenia:
    i. Ptot = 4*15 = 60W
    ii. 125 = Ts + 15*(6+0,4)
    iii. Ts = 29oC
    iv. Tj-s = 15*(6+0,4)=96oC
    v. Rth s-a ≤(29-25)/60
    vi. Rth s-a ≤0,07oC/W


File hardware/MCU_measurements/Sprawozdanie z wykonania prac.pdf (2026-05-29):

Politechnika Opolska
Sprawozdanie z przebiegu prac grupy
PRZEDMIOT: | Zarządzanie projektami elektronicznymi
KIERUNEK STUDIÓW: | EiSK | ROK STUDIÓW: III
SPECJALNOŚĆ: | -
SEMESTR: | VI | ROK AKADEMICKI: 2025/2026

Temat:
Sprawozdanie i ocena wyników pracy projektowej oraz współpracy członków grupy

Project owner:

Nazwisko: | Imię: | Nazwisko: | Imię:
1. Wacławczyk Jakub | 3.
2. 4.

1. Wstęp i założenia projektowe
Celem projektu było zaprojektowanie mikroprocesorowego inwertera wyspowego o mocy 1kW zasilanego akumulatorem 24V.
1.1 Podział na zadania
- Scrum master – Mateusz Skipor
- Przetwornica DC/DC – Marcin Majchrowski
- Falownik 325 DC – Grzegorz Rak
- Mikrokontroler + program – Łukasz Rasztar
- Sterownik elementów mocy – Tobiasz Kandziora
- Pomiar prądu i napięcia wyjściowego – Mateusz Skipor
- Projekt konstrukcyjny urządzenia – Jakub Wacławczyk

1.2 Kamienie milowe wraz z szacowanym czasem wykonania

a.Zapoznanie się z tematyką – 1 tydzień b.Symulacje i analiza różnych rozwiązań – 2 tygodnie
c. Zgranie poszczególnych bloków funkcjonalnych w jedną całość – 2 tygodnie
d.Projekt schematu całego urządzenia – 2 tygodnie
e.Projekt PCB całego urządzenia – 3 tygodnie
f. Wizualizacja całego urządzenia – 1 tydzień – równolegle z punktem 7
g.Algorytm sterowania elementami mocy: 1 tydzień
h.Implementacja programu oraz uruchomienie prototypu – 3 tygodnie
2. Realizacja projektu
Projekt został wykonany w ustalonym czasie. Wszystkie założenia funkcjonalne zostały zaprojektowane zgodnie z wymaganiami początkowymi. Prace były realizowane etapowo z drobnym ustępstwem zarówno na plus jak i minus od początkowego harmonogramu. Podział obowiązków został w większości zachowany. Konieczne były drobne zmiany organizacyjne wynikające z dynamiki realizacji projektu oraz konieczności dostosowania harmonogramu prac.

3. Napotkane problemy
W kilku przypadkach konieczne było poświęcenie większej ilości czasu lub uwagi konkretnym etapom pracy. W początkowym podziale zadań nie były jednoznacznie określone wszystkie zadania wraz z przypisaniem ich członkowi grupy. Poszczególne zadania wymagały nakładu pracy oraz koordynacji pomiędzy członkami zespołu.
4. Narzędzia użyte do kontroli nad pracą grupową
- Github – zbiór wszystkich prac wraz z dokumentacjami i materiałami pomocniczymi.
- Messenger – główne medium komunikacji
- Discord – dodatkowe medium komunikacji.
5. Uwagi i wnioski
Cały przebieg prac został zrealizowany prawidłowo. Projekt został ukończony w wyznaczonych ramach czasowych. Napotkane problemy zostały rozwiązane w trakcie realizacji prac. Użyte narzędzia były wystarczające do zarządzania całością projektu. W przyszłych projektach należałoby poświęcić więcej uwagi na planowanie działań, dokładne rozpisanie zadań każdego członka grupy oraz wprowadzenie większej kontroli nad realizacją ustalonych terminów.

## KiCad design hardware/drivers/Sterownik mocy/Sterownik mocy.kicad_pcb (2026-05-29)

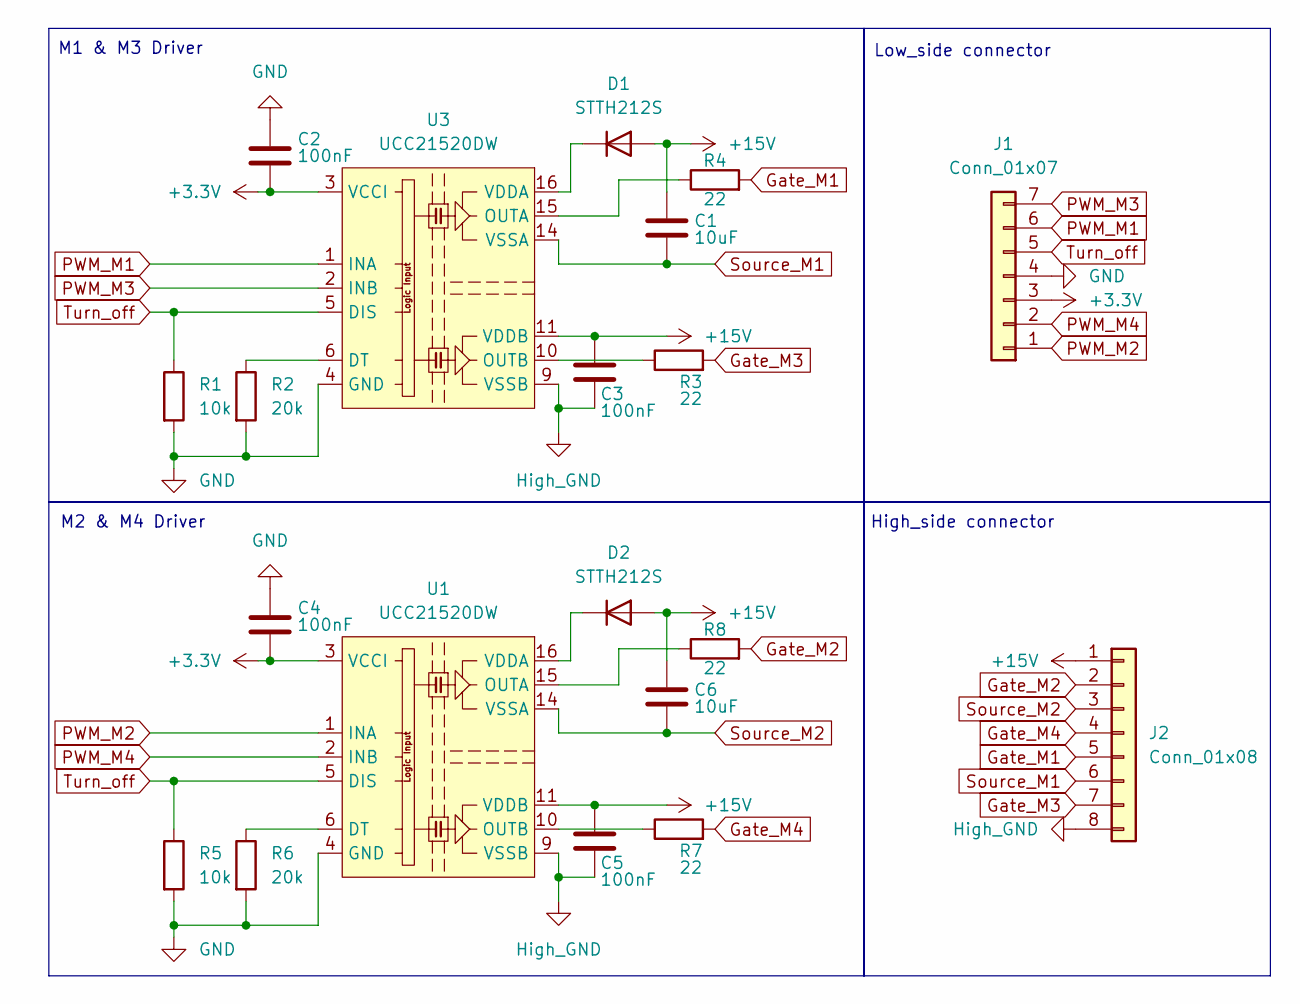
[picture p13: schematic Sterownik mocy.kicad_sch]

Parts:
C1, C6: 10uF; C_1206_3216Metric
C2, C3, C4, C5: 100nF; C_1206_3216Metric
D1, D2: STTH212S; D_SMC
J1: Conn_01x07; PinHeader_1x07_P1.00mm_Vertical
J2: Conn_01x08; PhoenixContact_MCV_1,5_8-G-5.08_1x08_P5.08mm_Vertical
R1, R5: 10k; R_0603_1608Metric
R2, R6: 20k; R_0603_1608Metric
R3, R4, R7, R8: 22; R_0603_1608Metric
U1, U3: UCC21520DW; SOIC-16W_7.5x10.3mm_P1.27mm

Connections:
+3.3V: C2.1, C4.1, J1.3, U1.3 (VCCI), U1.8 (VCCI), U3.3 (VCCI), U3.8 (VCCI)
+15V: C1.2, C3.2, C5.2, C6.2, D1.2 (A), D2.2 (A), J2.1, U1.11 (VDDB), U3.11 (VDDB)
GND: C2.2, C4.2, J1.4, R1.2, R2.2, R5.2, R6.2, U1.4 (GND), U3.4 (GND)
Gate_M1: J2.5, R4.2
Gate_M2: J2.2, R8.2
Gate_M3: J2.7, R3.2
Gate_M4: J2.4, R7.2
High_GND: C3.1, C5.1, J2.8, U1.9 (VSSB), U3.9 (VSSB)
unnamed: D1.1 (K), U3.16 (VDDA)
unnamed: D2.1 (K), U1.16 (VDDA)
unnamed: R6.1, U1.6 (DT)
unnamed: R8.1, U1.15 (OUTA)
unnamed: R7.1, U1.10 (OUTB)
unnamed: R2.1, U3.6 (DT)
unnamed: R4.1, U3.15 (OUTA)
unnamed: R3.1, U3.10 (OUTB)
PWM_M1: J1.6, U3.1 (INA)
PWM_M2: J1.1, U1.1 (INA)
PWM_M3: J1.7, U3.2 (INB)
PWM_M4: J1.2, U1.2 (INB)
Source_M1: C1.1, J2.6, U3.14 (VSSA)
Source_M2: C6.1, J2.3, U1.14 (VSSA)
Turn_off: J1.5, R1.1, R5.1, U1.5 (DIS), U3.5 (DIS)

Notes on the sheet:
M2 & M4 Driver
Low_side connector
High_side connector
M1 & M3 Driver

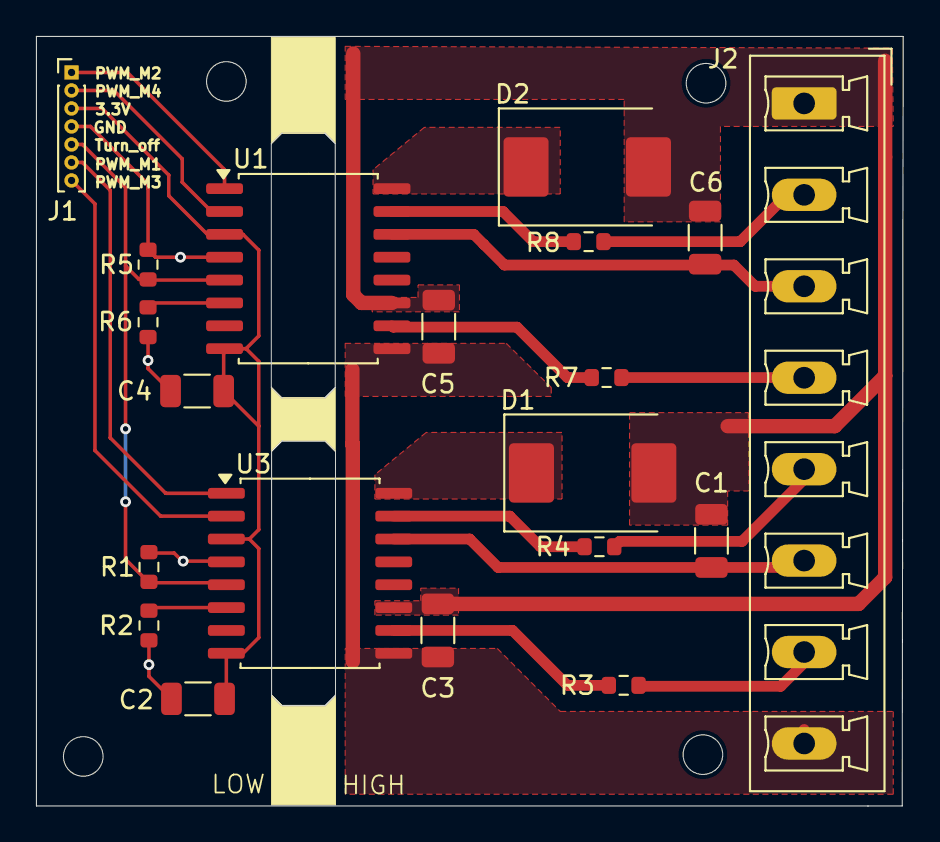
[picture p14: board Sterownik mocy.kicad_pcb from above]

Board: 2 copper layers, 48.1 x 42.8 mm, 20 parts (0 on the bottom side), 23 nets.

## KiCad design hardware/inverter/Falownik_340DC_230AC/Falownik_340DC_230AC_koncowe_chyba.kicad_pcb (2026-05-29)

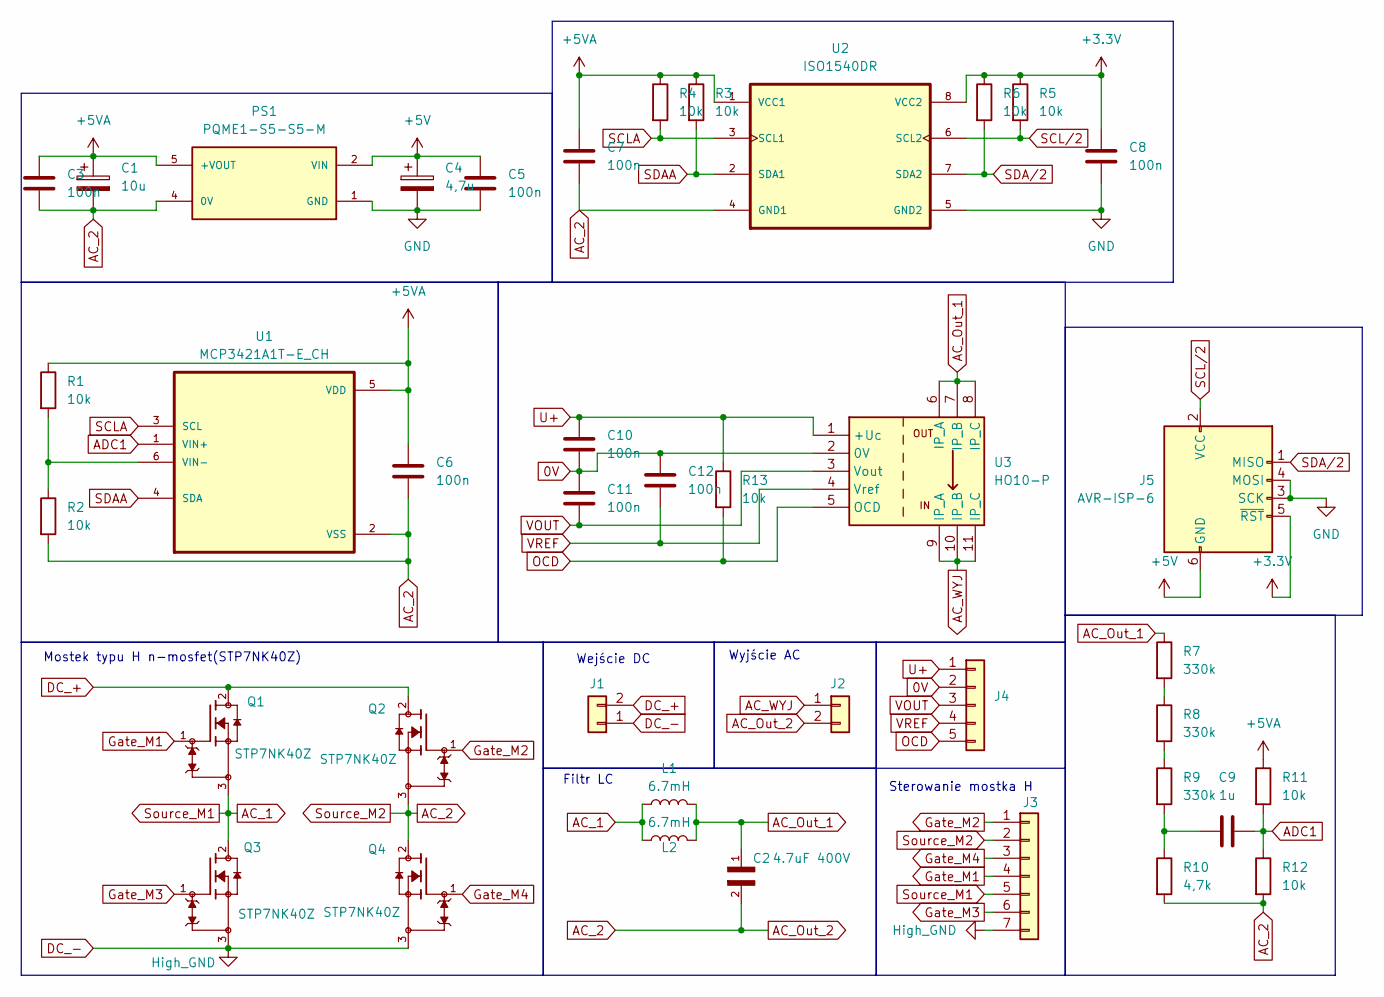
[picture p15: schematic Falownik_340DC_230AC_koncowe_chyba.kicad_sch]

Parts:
C1: 10u; CP_Radial_D7.5mm_P2.50mm
C2: B32674D3475K000; CAPRR2750W80L3150T1400H2450; PARTREV 2020-06
C3, C5, C6, C7, C8, C10, C11, C12: 100n; C_0805_2012Metric_Pad1.18x1.45mm_HandSolder
C4: 4,7u; CP_Radial_D7.5mm_P2.50mm
C9: 1u; C_Disc_D10.5mm_W5.0mm_P10.00mm
J1, J2: Conn_01x02; PhoenixContact_MCV_1,5_2-G-5.08_1x02_P5.08mm_Vertical
J3: Conn_01x07; PhoenixContact_MCV_1,5_7-G-5.08_1x07_P5.08mm_Vertical
J4: Conn_01x05; PinSocket_1x05_P2.54mm_Vertical
J5: AVR-ISP-6
L1, L2: 6.7mH; L_Toroid_Horizontal_D69.1mm_P63.20mm_Vishay_TJ9
PS1: PQME1-S5-S5-M; CONV_PQME1-S5-S5-M; PARTREV 1.0
Q1, Q2, Q3, Q4: STP7NK40Z; TO255P1020X450X1968-3B; PARTREV 1
R1, R2, R3, R4, R5, R6, R11, R12, R13: 10k; R_0805_2012Metric_Pad1.20x1.40mm_HandSolder
R7, R8, R9: 330k; R_Axial_DIN0516_L15.5mm_D5.0mm_P30.48mm_Horizontal
R10: 4,7k; R_Axial_DIN0516_L15.5mm_D5.0mm_P30.48mm_Horizontal
U1: MCP3421A1T-E_CH; SOT95P280X145-6N
U2: ISO1540DR; SOIC127P599X175-8N; PARTREV 02/2019
U3: HO10-P; current_sensor

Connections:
0V: C10.2, C11.1, C12.1, J4.2, U3.2 (0V)
+3.3V: C8.1, J5.5 (~RST), R5.1, R6.1, U2.8 (VCC2)
+5V: C4.1, C5.1, J5.6 (GND), PS1.2 (VIN)
+5VA: C1.1, C3.1, C6.1, C7.1, PS1.5 (+VOUT), R1.1, R3.1, R4.1, R11.1, U1.5 (VDD), U2.1 (VCC1)
AC_1: J3.5, L1.1, L2.1, Q1.3, Q3.2
AC_2: C1.2, C2.2, C3.2, C6.2, C7.2, J2.2, J3.2, PS1.4 (0V), Q2.3, Q4.2, R2.2, R10.2, R12.2, U1.2 (VSS), U2.4 (GND1)
AC_Out_1: C2.1, L1.2, L2.2, R7.1, U3.6 (IP_A), U3.7 (IP_B), U3.8 (IP_C)
AC_WYJ: J2.1, U3.9 (IP_A), U3.10 (IP_B), U3.11 (IP_C)
ADC1: C9.2, R11.2, R12.1, U1.1 (VIN+)
DC_+: J1.2, Q1.2, Q2.2
DC_-: J1.1, J3.7, Q3.3, Q4.3
GND: C4.2, C5.2, C8.2, J5.3 (SCK), J5.4 (MOSI), PS1.1 (GND), U2.5 (GND2)
Gate_M1: J3.4, Q1.1
Gate_M2: J3.1, Q2.1
Gate_M3: J3.6, Q3.1
Gate_M4: J3.3, Q4.1
unnamed: C9.1, R9.2, R10.1
unnamed: R7.2, R8.1
unnamed: R8.2, R9.1
unnamed: R1.2, R2.1, U1.6 (VIN-)
OCD: J4.5, R13.2, U3.5 (OCD)
SCLA: R4.2, U1.3 (SCL), U2.3 (SCL1)
SCL/2: J5.2 (VCC), R5.2, U2.6 (SCL2)
SDAA: R3.2, U1.4 (SDA), U2.2 (SDA1)
SDA/2: J5.1 (MISO), R6.2, U2.7 (SDA2)
U+: C10.1, J4.1, R13.1, U3.1 (+Uc)
VOUT: C11.2, J4.3, U3.3 (Vout)
VREF: C12.2, J4.4, U3.4 (Vref)

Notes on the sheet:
Wyjście AC
Sterowanie mostka H
Wejście DC
Mostek typu H n-mosfet(STP7NK40Z)
Filtr LC

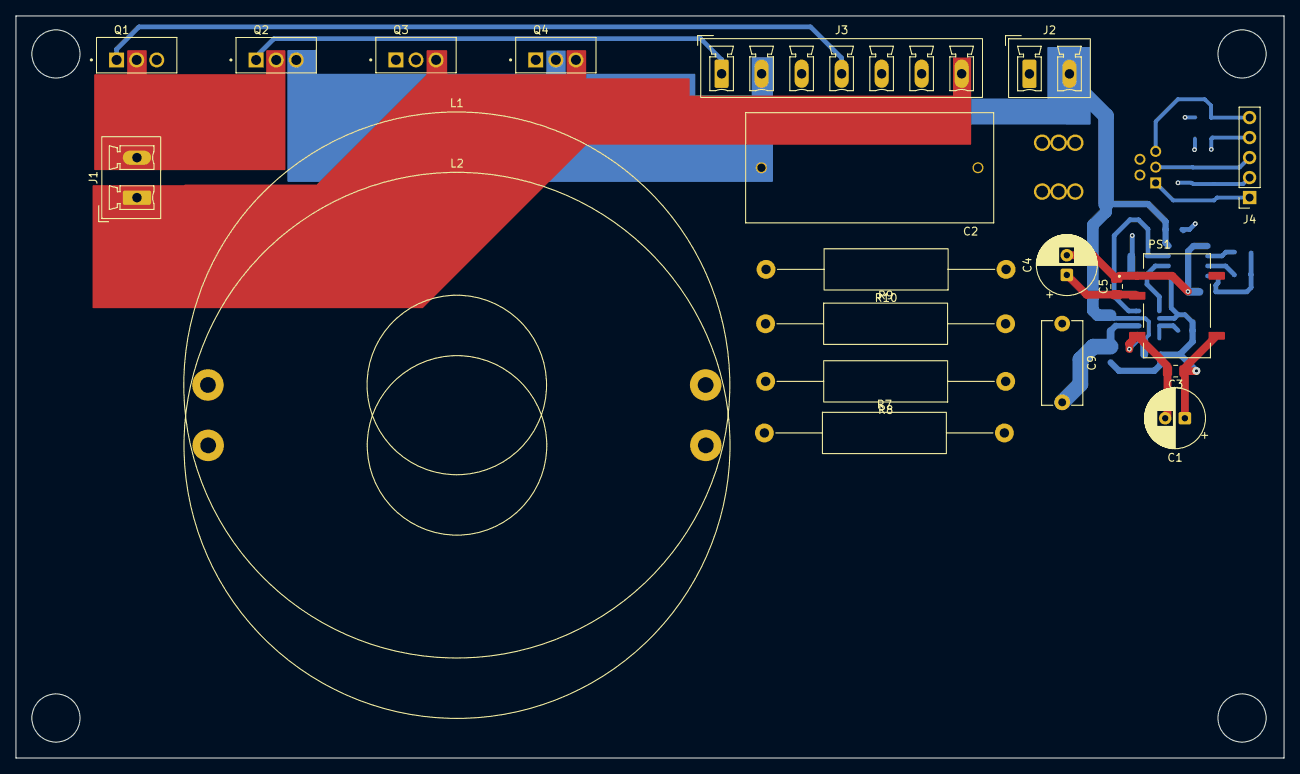
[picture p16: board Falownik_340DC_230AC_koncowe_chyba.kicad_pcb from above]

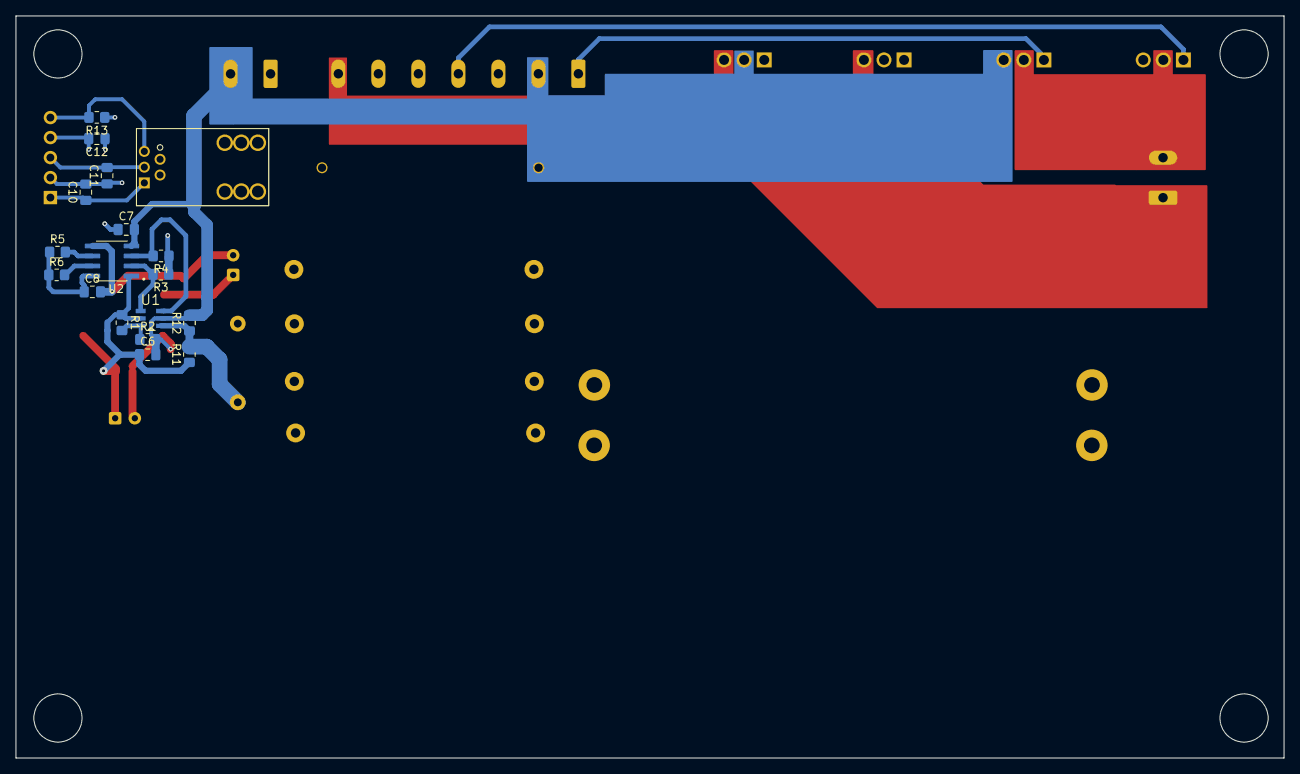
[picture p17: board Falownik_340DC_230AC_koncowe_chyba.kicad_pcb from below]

Board: 4 copper layers, 161.0 x 94.2 mm, 39 parts (18 on the bottom side), 28 nets.

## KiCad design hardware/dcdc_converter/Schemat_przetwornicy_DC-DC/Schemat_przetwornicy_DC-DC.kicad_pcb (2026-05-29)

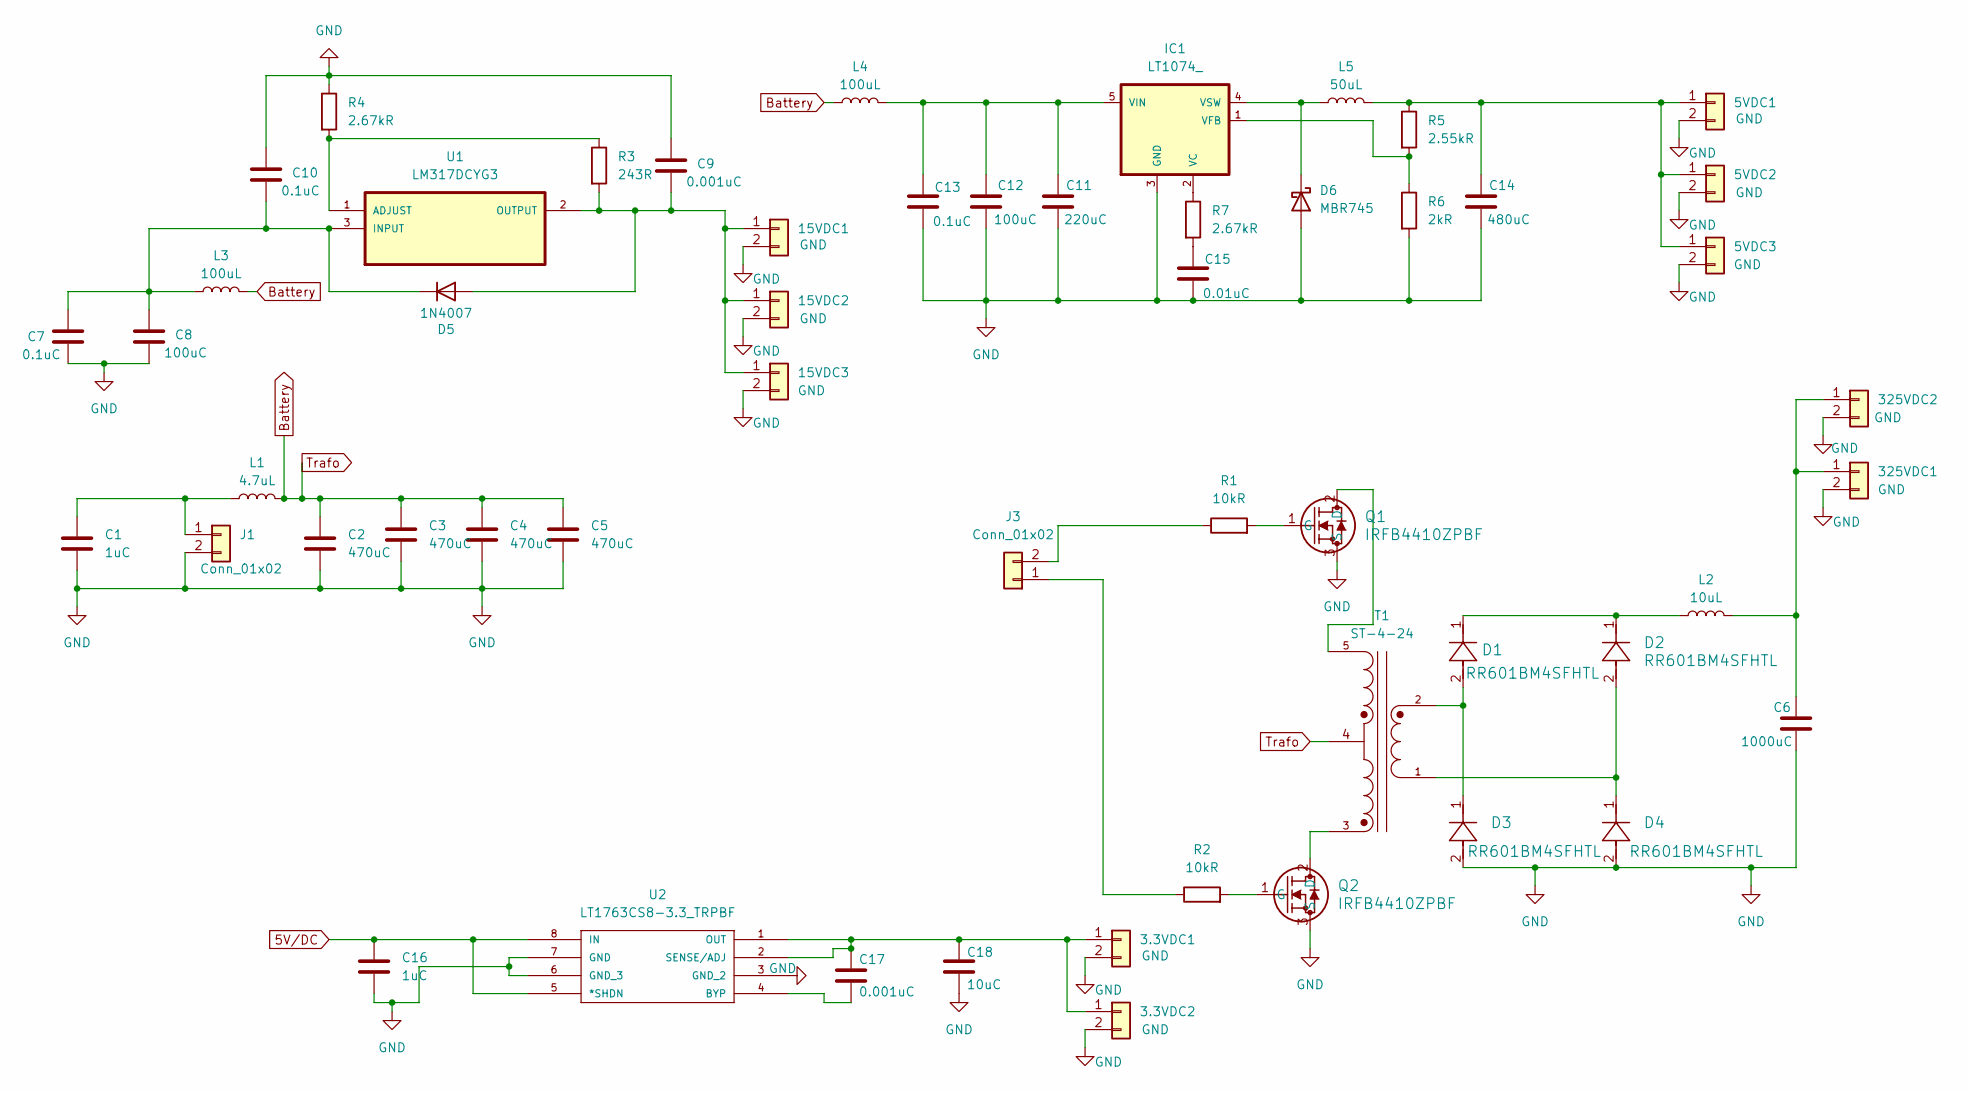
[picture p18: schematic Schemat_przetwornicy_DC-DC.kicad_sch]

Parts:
3.3VDC1, 3.3VDC2, 5VDC1, 5VDC2, 15VDC1, 15VDC2, 325VDC2: GND; PhoenixContact_MCV_1,5_2-G-3.5_1x02_P3.50mm_Vertical
5VDC3, 15VDC3, 325VDC1: GND; PinHeader_1x02_P2.54mm_Vertical
C1, C16: 1uC; CP_EIA-1608-08_AVX-J
C2, C3, C4, C5: 470uC; C_Radial_D16.0mm_H25.0mm_P7.50mm
C6: 1000uC; C_Radial_D16.0mm_H25.0mm_P7.50mm
C7, C10, C13: 0.1uC; CP_EIA-1608-08_AVX-J
C8, C12: 100uC; C_Radial_D16.0mm_H25.0mm_P7.50mm
C9, C17: 0.001uC; CP_EIA-1608-08_AVX-J
C11: 220uC; C_Radial_D16.0mm_H25.0mm_P7.50mm
C14: 480uC; C_Radial_D16.0mm_H25.0mm_P7.50mm
C15: 0.01uC; CP_EIA-1608-08_AVX-J
C18: 10uC; CP_EIA-1608-08_AVX-J
D1, D2, D3, D4: RR601BM4SFHTL; DIO_RR601BM4_ROM-M
D5: 1N4007; D_DO-41_SOD81_P10.16mm_Horizontal
D6: MBR745; TO-220-2_Vertical
IC1: LT1074_; TO220-5
J1: Conn_01x02; PhoenixContact_MCV_1,5_2-G-3.5_1x02_P3.50mm_Vertical
J3: Conn_01x02; PinHeader_1x02_P2.54mm_Vertical
L1: 4.7uL; L_2010_5025Metric_Pad1.52x2.65mm_HandSolder
L2: 10uL; L_2010_5025Metric_Pad1.52x2.65mm_HandSolder
L3, L4: 100uL; L_2010_5025Metric_Pad1.52x2.65mm_HandSolder
L5: 50uL; L_2010_5025Metric_Pad1.52x2.65mm_HandSolder
Q1, Q2: IRFB4410ZPBF; QNMOS1G2D3S_TO-220AB_INF
R1, R2: 10kR; R_0201_0603Metric
R3: 243R; R_0201_0603Metric
R4, R7: 2.67kR; R_0201_0603Metric
R5: 2.55kR; R_0201_0603Metric
R6: 2kR; R_0201_0603Metric
T1: ST-4-24; Transformer_Myrra_EI30-5_44000_Horizontal
U1: LM317DCYG3; SOT230P700X180-4N
U2: LT1763CS8-3.3_TRPBF; SO-8_S; MANUFACTURER_PART_NUMBER lt1763cs8

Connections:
5V/DC: C16.1, U2.5 (*SHDN), U2.8 (IN)
Battery: C2.1, C3.1, C4.1, C5.1, L1.2, L3.2, L4.1, T1.4
GND: 3.3VDC1.2, 3.3VDC2.2, 5VDC1.2, 5VDC2.2, 5VDC3.2, 15VDC1.2, 15VDC2.2, 15VDC3.2, 325VDC1.2, 325VDC2.2, C1.2, C2.2, C3.2, C4.2, C5.2, C6.2, C7.2, C8.2, C9.1, C10.1, C11.2, C12.2, C13.2, C14.2, C15.2, C16.2, C18.2, D3.2, D4.2, D6.2 (A), IC1.3 (GND), J1.2, Q1.3 (S), Q2.3 (S), R4.1, R6.2, U2.3 (GND_2), U2.6 (GND_3), U2.7 (GND); also elsewhere on the board
unnamed: 3.3VDC1.1, 3.3VDC2.1, C17.1, C18.1, U2.1 (OUT), U2.2 (SENSE/ADJ)
unnamed: 5VDC1.1, 5VDC2.1, 5VDC3.1, C14.1, L5.2, R5.1
unnamed: 15VDC1.1, 15VDC2.1, 15VDC3.1, C9.2, D5.2 (A), R3.2, U1.2 (OUTPUT), U1.4 (OUTPUT)
unnamed: 325VDC1.1, 325VDC2.1, C6.1, L2.2
unnamed: C15.1, R7.2
unnamed: D1.1, D2.1, L2.1
unnamed: D1.2, D3.1, T1.2
unnamed: D2.2, D4.1, T1.1
unnamed: C7.1, C8.1, C10.2, D5.1 (K), L3.1, U1.3 (INPUT)
unnamed: D6.1 (K), IC1.4 (VSW), L5.1
unnamed: IC1.2 (VC), R7.1
unnamed: IC1.1 (VFB), R5.2, R6.1
unnamed: C11.1, C12.1, C13.1, IC1.5 (VIN), L4.2
unnamed 16: C1.1, J1.1, L1.1; also elsewhere on the board
unnamed: J3.1, R2.1
unnamed: J3.2, R1.1
unnamed: Q1.2 (D), T1.5
unnamed: Q1.1 (G), R1.2
unnamed: Q2.2 (D), T1.3
unnamed: Q2.1 (G), R2.2
unnamed: R3.1, R4.2, U1.1 (ADJUST)
unnamed: C17.2, U2.4 (BYP)

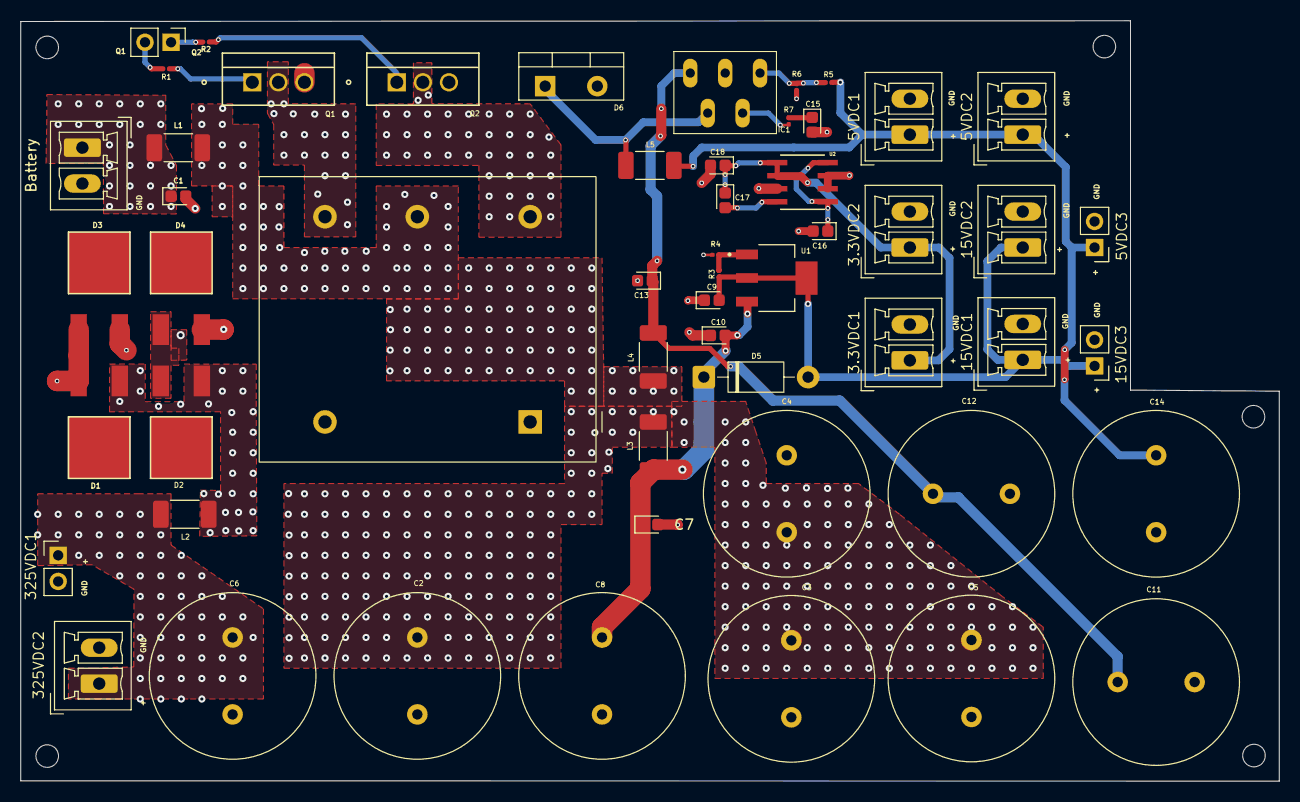
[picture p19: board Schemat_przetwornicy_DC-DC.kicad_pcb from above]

Board: 4 copper layers, 122.7 x 74.1 mm, 54 parts (0 on the bottom side), 25 nets.

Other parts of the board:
Battery: Conn_01x02; PhoenixContact_MCV_1,5_2-G-3.5_1x02_P3.50mm_Vertical

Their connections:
GND: Battery.2; also elsewhere on the board
unnamed 16: Battery.1; also elsewhere on the board

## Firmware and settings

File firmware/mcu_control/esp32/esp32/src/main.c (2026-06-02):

#include <stdbool.h>

#include "esp_log.h"
#include "esp_timer.h"
#include "freertos/FreeRTOS.h"
#include "freertos/task.h"

#include "oled.h"
#include "pwm.h"
#include "fan_pwm.h"

#define PIN_FAN 27


static const pwm_hbridge_config_t s_pwm_config = {
    .high_side_gpio = 25,
    .low_side_gpio = 26,
    .carrier_frequency_hz = 20000U,
    .timer_resolution_hz = 1000000U,
    .deadtime_ticks = 2U,
};

static const char *TAG = "falownik";

static const float EXAMPLE_FREQUENCY_HZ = 50.0f;
static const float EXAMPLE_AC_VOLTAGE_V = 230.0f;
static const float EXAMPLE_AC_CURRENT_A = 2.5f;
static const float EXAMPLE_DC_VOLTAGE_V = 24.0f;
static const float EXAMPLE_DC_CURRENT_A = 10.0f;
static const float EXAMPLE_TEMP_T1_C = 36.0f;
static const float EXAMPLE_TEMP_T2_C = 31.0f;
static const float EXAMPLE_FAN_SPEED_PERCENT = 25.0f;

static controller_t s_controller = {
    .enabled = true,
    .frequency_hz = EXAMPLE_FREQUENCY_HZ,
    .amplitude_percent = 80.0f,
    .ac_voltage_v = EXAMPLE_AC_VOLTAGE_V,
    .ac_current_a = EXAMPLE_AC_CURRENT_A,
    .dc_voltage_v = EXAMPLE_DC_VOLTAGE_V,
    .dc_current_a = EXAMPLE_DC_CURRENT_A,
    .temp_t1_c = EXAMPLE_TEMP_T1_C,
    .temp_t2_c = EXAMPLE_TEMP_T2_C,
    .fan_speed_percent = EXAMPLE_FAN_SPEED_PERCENT,
    .phase = 0.0f,
    .last_pwm_update_us = 0,
    .last_ui_update_us = 0,
    .ui_dirty = true,
};

void app_main(void)
{
    ESP_LOGI(TAG, "Start");

    pwm_init(&s_pwm_config);
    oled_init();
    fan_init(PIN_FAN);

    /* I2C scanner removed; no scan performed here */

    oled_show_boot();
    oled_render_ui(&s_controller);
    s_controller.last_ui_update_us = esp_timer_get_time();

    while (true) {
        pwm_update(&s_controller);
        /* update fan PWM from controller state */
        fan_set_speed_percent(s_controller.fan_speed_percent);

        int64_t now_us = esp_timer_get_time();
        if (s_controller.ui_dirty || (now_us - s_controller.last_ui_update_us) > 200000) {
            oled_render_ui(&s_controller);
            s_controller.last_ui_update_us = now_us;
            s_controller.ui_dirty = false;
        }

        vTaskDelay(pdMS_TO_TICKS(20));
    }
}

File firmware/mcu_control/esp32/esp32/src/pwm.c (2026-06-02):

#include <math.h>
#include <stdbool.h>

#include "driver/ledc.h"
#include "esp_err.h"
#include "esp_timer.h"

#include "pwm.h"

#define PWM_MIN_DUTY 0.05f
#define PWM_MAX_DUTY 0.95f
#define PWM_TWO_PI 6.28318530718f

// Choose LEDC resolution (bits)
#define LEDC_DUTY_RES_BITS 10
#define LEDC_MAX_DUTY ((1 << LEDC_DUTY_RES_BITS) - 1)

static bool s_outputs_enabled = false;
static pwm_hbridge_config_t s_config;

static float pwm_clampf(float value, float min_value, float max_value)
{
    if (value < min_value) return min_value;
    if (value > max_value) return max_value;
    return value;
}

static float pwm_wrap_phase(float phase)
{
    while (phase >= PWM_TWO_PI) phase -= PWM_TWO_PI;
    while (phase < 0.0f) phase += PWM_TWO_PI;
    return phase;
}

static float pwm_compute_delta_seconds(controller_t *controller)
{
    int64_t now_us = esp_timer_get_time();
    if (controller->last_pwm_update_us == 0) {
        controller->last_pwm_update_us = now_us;
        return 0.0f;
    }
    float delta_seconds = (float)(now_us - controller->last_pwm_update_us) / 1000000.0f;
    controller->last_pwm_update_us = now_us;
    return delta_seconds;
}

static float pwm_compute_normalized_duty(controller_t *controller, float delta_seconds)
{
    if (!controller->enabled) {
        controller->phase = 0.0f;
        return 0.0f;
    }

    float amplitude = pwm_clampf(controller->amplitude_percent, 0.0f, 100.0f) / 100.0f;
    controller->phase = pwm_wrap_phase(controller->phase + PWM_TWO_PI * controller->frequency_hz * delta_seconds);
    float normalized = 0.5f + 0.45f * amplitude * sinf(controller->phase);
    return pwm_clampf(normalized, PWM_MIN_DUTY, PWM_MAX_DUTY);
}

static void pwm_set_ledc_duty(int channel, uint32_t duty)
{
    ESP_ERROR_CHECK(ledc_set_duty(LEDC_HIGH_SPEED_MODE, (ledc_channel_t)channel, duty));
    ESP_ERROR_CHECK(ledc_update_duty(LEDC_HIGH_SPEED_MODE, (ledc_channel_t)channel));
}

void pwm_init(const pwm_hbridge_config_t *config)
{
    // copy config
    s_config = *config;

    // basic validation
    if (s_config.carrier_frequency_hz == 0) {
        // avoid division by zero / invalid timer
        s_config.carrier_frequency_hz = 10000;
    }

    // configure LEDC timer
    ledc_timer_config_t timer_cfg = {
        .speed_mode = LEDC_HIGH_SPEED_MODE,
        .duty_resolution = LEDC_DUTY_RES_BITS,
        .timer_num = LEDC_TIMER_0,
        .freq_hz = (int)s_config.carrier_frequency_hz,
        .clk_cfg = LEDC_AUTO_CLK,
    };
    ESP_ERROR_CHECK(ledc_timer_config(&timer_cfg));

    // configure two channels: high side -> channel 0, low side -> channel 1
    ledc_channel_config_t ch_high = {
        .gpio_num = s_config.high_side_gpio,
        .speed_mode = LEDC_HIGH_SPEED_MODE,
        .channel = LEDC_CHANNEL_0,
        .intr_type = LEDC_INTR_DISABLE,
        .timer_sel = LEDC_TIMER_0,
        .duty = 0,
        .hpoint = 0,
    };

    ledc_channel_config_t ch_low = {
        .gpio_num = s_config.low_side_gpio,
        .speed_mode = LEDC_HIGH_SPEED_MODE,
        .channel = LEDC_CHANNEL_1,
        .intr_type = LEDC_INTR_DISABLE,
        .timer_sel = LEDC_TIMER_0,
        .duty = 0,
        .hpoint = 0,
    };

    ESP_ERROR_CHECK(ledc_channel_config(&ch_high));
    ESP_ERROR_CHECK(ledc_channel_config(&ch_low));

    // start with outputs forced low
    pwm_set_ledc_duty(LEDC_CHANNEL_0, 0);
    pwm_set_ledc_duty(LEDC_CHANNEL_1, 0);
    s_outputs_enabled = false;
}

void pwm_update(controller_t *controller)
{
    float delta_seconds = pwm_compute_delta_seconds(controller);
    float normalized = pwm_compute_normalized_duty(controller, delta_seconds);
    // period in microseconds
    float period_us = 1000000.0f / (float)s_config.carrier_frequency_hz;
    // interpret s_config.deadtime_ticks as deadtime in microseconds for this LEDC implementation
    float deadtime_us = (float)s_config.deadtime_ticks;

    // deadtime fraction of period (clamp small/max to avoid disabling PWM)
    float dead_frac = 0.0f;
    if (period_us > 0.0f) {
        dead_frac = pwm_clampf(deadtime_us / period_us, 0.0f, 0.45f);
    }

    // create complementary outputs with software deadtime by shrinking both pulses by half the deadtime
    float high_adj = pwm_clampf(normalized - dead_frac * 0.5f, 0.0f, 1.0f);
    float low_adj = pwm_clampf((1.0f - normalized) - dead_frac * 0.5f, 0.0f, 1.0f);

    uint32_t duty_high = (uint32_t)(high_adj * (float)LEDC_MAX_DUTY);
    uint32_t duty_low = (uint32_t)(low_adj * (float)LEDC_MAX_DUTY);

    if (controller->enabled) {
        if (!s_outputs_enabled) s_outputs_enabled = true;
        // drive complementary channels with software deadtime
        pwm_set_ledc_duty(LEDC_CHANNEL_0, duty_high);
        pwm_set_ledc_duty(LEDC_CHANNEL_1, duty_low);
    } else {
        pwm_set_ledc_duty(LEDC_CHANNEL_0, 0);
        pwm_set_ledc_duty(LEDC_CHANNEL_1, 0);
        s_outputs_enabled = false;
        controller->phase = 0.0f;
    }
}

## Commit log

2026-03-30 Add files via upload
    Schemat falownika (brak PCB)
2026-05-25 Replace inverter zip with extracted files
    [Falownik_340DC_230AC_koncowe_chyba.kicad_pcb, Falownik_340DC_230AC_koncowe_chyba.kicad_sch]
2026-05-26 Add measurement files
    [falownik.f3d, pcb.kicad_pcb, pcb.kicad_sch]
2026-05-29 Aktualizacja projektu
    [Falownik_340DC_230AC_koncowe_chyba.kicad_pcb, Falownik_340DC_230AC_koncowe_chyba.kicad_sch, Schemat_przetwornicy_DC-DC.kicad_pcb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]
2026-06-02 Update ESP32 firmware and clean ignored files
